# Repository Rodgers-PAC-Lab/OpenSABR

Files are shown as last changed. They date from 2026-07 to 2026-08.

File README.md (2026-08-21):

# OpenSABR

OpenSABR stands for "Open-source System for Auditory Brainstem Response".
This repository was previously named "ABR2025".

## Introduction

This repository contains code to implement the ABR measuring system described
in [Gargiullo et al](https://www.biorxiv.org/content/10.64898/2025.12.17.694771v1), 
as well as the analysis scripts needed to replicate the figures in that paper.

The repository is structured as follows:
- `./` - The toplevel directory, containing this README file
- `./hardware_designs` - Design files, bill of materials, and other information about 
physically building the system.
- `./src/opensabr` - source code for analysis and GUI. Import like `import opensabr`
- `./src/opensabr/gui` - A Python module for running the graphical user interface (GUI) 
to take ABR data. It can be imported like `import opensabr.gui`. This code is 
run on a desktop PC connected to the ABR measuring system hardware.
- `./scripts` - A folder of demo scripts that generate the figures in the
paper, using data that we collected and have shared on Zenodo. These scripts 
are meant to be run one at a time, not imported and called by other scripts. 

## Requirements

We used Python 3.11. Newer versions may also work but we did not test them.
- pyproject.toml contains a list of the required dependencies
- requirements-lock.txt includes the exact versions we used

For the analysis scripts (but not the GUI), the following repository is 
required. It should be on your PYTHONPATH so that it can be imported using
the syntax `import my`.
- `git clone git@github.com:Rodgers-PAC-Lab/my.git`

## Instructions

To build the hardware, refer to the file `./hardware_designs/README.md` for finding code and design files, then refer to the file `OpenSABR Build Guide.pdf` for assembly instructions. 

To run the GUI and measure ABR, refer to the file `./src/opensabr/gui/README`.

To run the analysis scripts and regenerate the figures included in the paper,
refer to the file `./scripts/README`.

## Installation of OpenSABR

A note about our package management approach:
- Repositories that are install-able (i.e., using a method like `pip install` or `python setup.py`) are cloned into `~/installed`
- Repositories that need to be importable (like `import reponame`) but are not install-able are cloned into `~/dev`, which is a directory on `$PYTHONPATH`. Two examples of repositories like this are ABRA and Rodgers-PAC-Lab:my.git

The reason for this distinction is because it can cause errors to mix these two kinds of repositories in the same directory.

### Clone the OpenSABR repo

Run the following commands:

```
cd ~/installed
git clone git@github.com:Rodgers-PAC-Lab/OpenSABR
cd OpenSABR
```

Then pick one of the following installation approaches.
- Option A is easier and does not pin any versions of dependencies, so you will get the newest available
- Option B will download the exact versions of the repositories we used. This is mainly useful for reproducing our results exactly. This approach will only work on linux, since that is what we used.

### Option A: Typical install (no version pins)

```
conda create -n opensabr -c conda-forge python=3.11 pip ipython
conda activate opensabr
conda install -c conda-forge numpy scipy pandas matplotlib tqdm pyqt pyqtgraph pyserial pyarrow seaborn
pip install -e . --no-deps
```

### Option B: Reproducible install from lock (linux-64 only)

```
conda create -n opensabr --file opensabr-conda-lock.txt
conda activate opensabr
pip install -e . --no-deps
```

Now you have installed opensabr. Try `import opensabr` to be sure.

You can stop here if you all you want to do is run or use OpenSABR. You only have to continue if you want to reproduce the comparisons to ABRpresto and ABRA that were made in the paper.

## Installation of other ABR software used as a comparison in the paper

In the paper we also compared our analysis software to two others. If you wish to reproduce this comparison, you will need to install them.

- ABRA, installed into a separate conda environment called "abra"
- ABRpresto, installed into a separate conda environment called "abrpresto"

You do not need to install these others if you just want to run OpenSABR.

### Installing ABRpresto

This is an "install-able" module. 

#### Clone repo

Run the following to install our fork. Our demo scripts require the use of our fork, which contains only minor modifications.

```
cd ~/installed 
git clone git@github.com:Rodgers-PAC-Lab/ABRpresto # our fork
cd ABRpresto
git checkout dev # our branch with fixes
```

Then pick one of the following installation approaches, A (flexible) or B (reproducible), analogous to the options above.

#### Option A: Typical install (no version pins)

```
conda create -n abrpresto -c conda-forge python=3.11 ipython pip
conda activate abrpresto
conda install -c conda-forge numpy scipy pandas matplotlib setuptools_scm pyarrow tqdm
pip install -e . --no-deps
```

#### Option B: Reproducible install from lock (linux-64 only)

```
conda create -n abrpresto --file abrpresto-conda-lock.txt
conda activate abrpresto
pip install -e . --no-deps
```

Now ABRpresto should be installed. Check with `import abrpresto`

### Installing ABRA

This is not an "install-able" module, but it is importable, so it need to go on PYTHONPATH.

#### Clone repo (must be under ~/dev or some location on PYTHONPATH)

```
cd ~/dev
git clone git@github.com:Rodgers-PAC-Lab/abranalysis # our fork
cd abranalysis
git checkout dev # our branch with fixes
```

As above, pick Option A or B.

#### Option A: Typical install (no version pins)

```
conda create -n abra -c conda-forge python=3.11 ipython pip
conda activate abra
conda install -c conda-forge numpy scipy pandas scikit-learn pytorch=*=cpu* keras tensorflow streamlit easydict "altair<5" pyarrow matplotlib tqdm
conda env config vars set PYTHONPATH=$HOME/dev
conda deactivate && conda activate abra   # reload so PYTHONPATH takes effect
```

#### Option B: Reproducible install from lock (linux-64 only)

```
conda create -n abra --file abra-conda-lock.txt
conda activate abra
conda env config vars set PYTHONPATH=$HOME/dev
conda deactivate && conda activate abra   # reload so PYTHONPATH takes effect
```

Now ABRA should be installed. Check with `import abranalyais`

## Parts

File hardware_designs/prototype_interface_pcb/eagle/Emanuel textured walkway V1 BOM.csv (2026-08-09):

Partlist exported from C:/Users/Bill/Dropbox/EAGLE/projects/
Alan Emanuel textured walkway/Emanuel textured walkway V1.sch at 4/9/2025 10:39 AM
Qty | Value | Device | Parts
3 | 1uF | C-USC0805 | C5, C6, C7
1 | 3.3 | TP-040-100 | 3.3
3 | 10uH | L-USL1812 | L1, L2, L3
1 | 22-23-2021 | 22-23-2021 | X1
1 | 74LS14D | 74LS14D | IC10
2 | 78E-5V | RECOM-R-78E | IC8, IC9
1 | 78E-12V | RECOM-R-78E | IC7
3 | 100/35 | CPOL-US140CLH-0810 | C2, C3, C4
3 | 100nF | C-USC0805 | C8, C9, C10
1 | 330/35 | CPOL-US140CLH-1010 | C1
6 | BTS3118N | BTS3118N | IC1, IC2, IC3, IC4, IC5, IC6
1 | EXTRA | ML16 | SV3
1 | I/O-1 | ML16 | SV2
1 | STEPPER | ML16 | SV1
1 | TEENSY_4.0_WITH_24-33 | TEENSY_4.0_WITH_24-33 | U$1
38 | TP-040-100 | TP-040-100 | +5B, 6, 7, 22, 23, 24, 25, 26, 27, 28, 29, 30, 31, 32, 33, E9, E10, E11, E12, E13, E14, E15, E16, EI1, EI2, EI3, EO1, EO2, EO3, MISO, MOSI, RX1, SCK, TX1, VI3, VS1, VS2, VS3
1 | TRCV-175-LARGE | TRCV-175-LARGE | J1

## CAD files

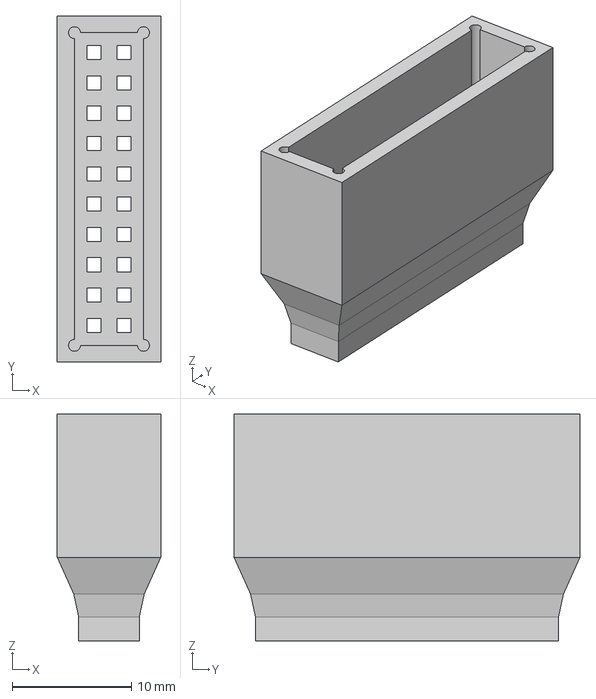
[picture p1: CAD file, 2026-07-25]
hardware_designs/3D_print_designs/2x10 male pin header spacer.step
8.68 x 29.0 x 19.0 mm

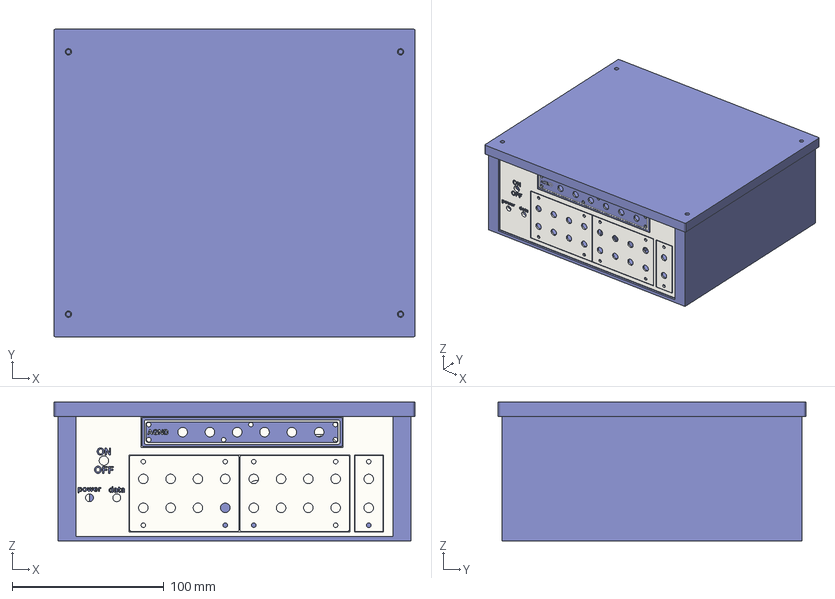
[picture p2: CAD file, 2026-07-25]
hardware_designs/3D_print_designs/Compact ABR enclosure.step
238.0 x 203.0 x 91.5 mm
face plate
Back plate
Lid

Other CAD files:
hardware_designs/3D_print_designs/2x10 male pin header spacer.3mf
hardware_designs/3D_print_designs/2x10 male pin header spacer.f3d
hardware_designs/3D_print_designs/Compact ABR enclosure.3mf
hardware_designs/3D_print_designs/Compact ABR enclosure.f3z

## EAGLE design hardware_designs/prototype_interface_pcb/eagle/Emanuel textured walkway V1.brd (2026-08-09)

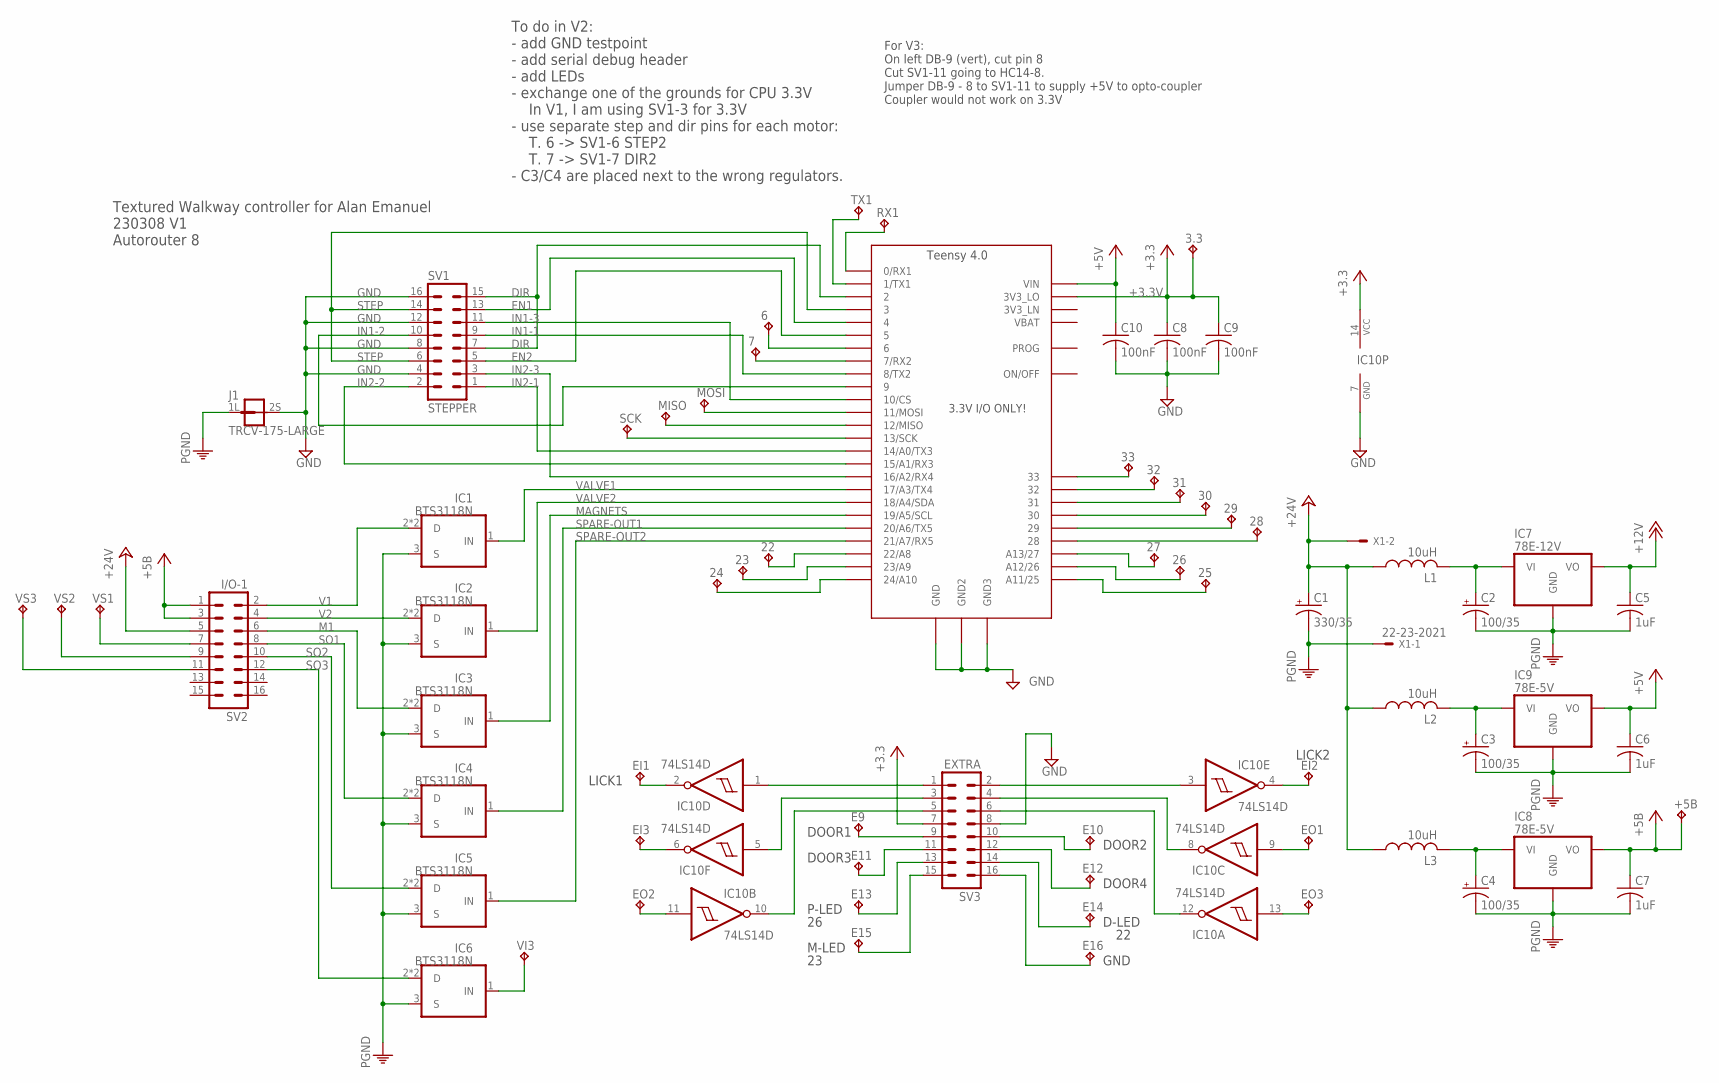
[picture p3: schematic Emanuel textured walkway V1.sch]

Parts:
3.3: 3.3; P1-040-100
6, 7, 22, 23, 24, 25, 26, 27, 28, 29, 30, 31, 32, 33: TP-040-100; P1-040-100
+5B: TP-040-100; P1-040-100
C1: 330/35; 140CLH-1010
C2, C3, C4: 100/35; 140CLH-0810
C5, C6, C7: 1uF; C0805
C8, C9, C10: 100nF; C0805
E9, E10, E11, E12, E13, E14, E15, E16: TP-040-100; P1-040-100
EI1, EI2, EI3: TP-040-100; P1-040-100
EO1, EO2, EO3: TP-040-100; P1-040-100
IC1, IC2, IC3, IC4, IC5, IC6: BTS3118N; SOT223
IC7: 78E-12V; RECOM-R-78E
IC8, IC9: 78E-5V; RECOM-R-78E
IC10: 74LS14D; SO14
J1: TRCV-175-LARGE; JUMPER-TRACE-CONVERT-LARGER-PADS-175
L1, L2, L3: 10uH; L1812
MISO: TP-040-100; P1-040-100
MOSI: TP-040-100; P1-040-100
RX1: TP-040-100; P1-040-100
SCK: TP-040-100; P1-040-100
SV1: STEPPER; ML16
SV2: I/O-1; ML16
SV3: EXTRA; ML16
TX1: TP-040-100; P1-040-100
U$1: TEENSY_4.0_WITH_24-33
VI3: TP-040-100; P1-040-100
VS1, VS2, VS3: TP-040-100; P1-040-100
X1: 22-23-2021

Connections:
+3.3V: 3.3.P$1, C8.1, C9.1, IC10.14 (VCC), SV3.7, U$1.3V3_LO
+5B: +5B.P$1, C7.1, IC8.3 (VO), SV2.1, SV2.3
+5V: C6.1, C10.1, IC9.3 (VO), U$1.VIN
+12V: C5.1, IC7.3 (VO)
+24V: C1.+, L1.1, L2.1, L3.1, SV2.5, X1.2
DIR: SV1.7, SV1.15, U$1.2
EN1: SV1.13, U$1.4
EN2: SV1.5, U$1.5
GND: C8.2, C9.2, C10.2, IC10.7 (GND), J1.2S (2), SV1.4, SV1.8, SV1.12, SV1.16, SV3.8, U$1.GND, U$1.GND2, U$1.GND3
IN1-1: SV1.9, U$1.8 (8/TX2)
IN1-2: SV1.10, U$1.9
IN1-3: SV1.11, U$1.10/CS
IN2-1: SV1.1, U$1.14/A0 (14/A0/TX3)
IN2-2: SV1.2, U$1.15/A1 (15/A1/RX3)
IN2-3: SV1.3, U$1.16/A2 (16/A2/RX4)
M1: IC3.2 (D), IC3.4 (D), SV2.6
MAGNETS: IC3.1 (IN), U$1.19/A5/SCL
unnamed: C2.+, IC7.1 (VI), L1.2
unnamed: C4.+, IC8.1 (VI), L3.2
unnamed: SV2.9, VS2.P$1
unnamed: SV2.11, VS3.P$1
unnamed: C3.+, IC9.1 (VI), L2.2
unnamed: IC6.1 (IN), VI3.P$1
unnamed: MOSI.P$1, U$1.11/MOSI
unnamed: MISO.P$1, U$1.12/MISO
unnamed: SV2.7, VS1.P$1
unnamed: SCK.P$1, U$1.13/SCK
unnamed: 22.P$1, U$1.22/A8
unnamed: 23.P$1, U$1.23/A9
unnamed: 24.P$1, U$1.24 (24/A10)
unnamed: 33.P$1, U$1.33
unnamed: 32.P$1, U$1.32
unnamed: 31.P$1, U$1.31
unnamed: 30.P$1, U$1.30
unnamed: 29.P$1, U$1.29
unnamed: 28.P$1, U$1.28
unnamed: 27.P$1, U$1.27 (A13/27)
unnamed: 26.P$1, U$1.26 (A12/26)
unnamed: 25.P$1, U$1.25 (A11/25)
unnamed: RX1.P$1, U$1.0/RX (0/RX1)
unnamed: TX1.P$1, U$1.1/TX (1/TX1)
unnamed: 6.P$1, U$1.6
unnamed: 7.P$1, U$1.7 (7/RX2)
unnamed: IC10.1 (I), SV3.1
unnamed: IC10.3 (I), SV3.2
unnamed: IC10.5 (I), SV3.3
unnamed: IC10.8 (O), SV3.4
unnamed: IC10.10 (O), SV3.5
unnamed: IC10.12 (O), SV3.6
unnamed: E9.P$1, SV3.9
unnamed: E11.P$1, SV3.11
unnamed: E13.P$1, SV3.13
unnamed: E15.P$1, SV3.15
unnamed: E10.P$1, SV3.10
unnamed: E12.P$1, SV3.12
unnamed: E14.P$1, SV3.14
unnamed: E16.P$1, SV3.16
unnamed: EI1.P$1, IC10.2 (O)
unnamed: EI3.P$1, IC10.6 (O)
unnamed: EI2.P$1, IC10.4 (O)
unnamed: EO3.P$1, IC10.13 (I)
unnamed: EO1.P$1, IC10.9 (I)
unnamed: EO2.P$1, IC10.11 (I)
PGND: C1.-, C2.-, C3.-, C4.-, C5.2, C6.2, C7.2, IC1.3 (S), IC2.3 (S), IC3.3 (S), IC4.3 (S), IC5.3 (S), IC6.3 (S), IC7.2 (GND), IC8.2 (GND), IC9.2 (GND), J1.1L (1), X1.1
SO1: IC4.2 (D), IC4.4 (D), SV2.8
SO2: IC5.2 (D), IC5.4 (D), SV2.10
SO3: IC6.2 (D), IC6.4 (D), SV2.12
SPARE-OUT1: IC4.1 (IN), U$1.20/A6 (20/A6/TX5)
SPARE-OUT2: IC5.1 (IN), U$1.21/A7 (21/A7/RX5)
STEP: SV1.6, SV1.14, U$1.3
V1: IC1.2 (D), IC1.4 (D), SV2.2
V2: IC2.2 (D), IC2.4 (D), SV2.4
VALVE1: IC1.1 (IN), U$1.17/A3 (17/A3/TX4)
VALVE2: IC2.1 (IN), U$1.18/A4/SDA

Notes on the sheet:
Textured Walkway controller for Alan Emanuel 230308 V1 Autorouter 8
To do in V2: - add GND testpoint - add serial debug header - add LEDs - exchange one of the grounds for CPU 3.3V In V1, I am using SV1-3 for 3.3V - use separate step and dir pins for each motor: T. 6 -> SV1-6 STEP2 T. 7 -> SV1-7 DIR2 - C3/C4 are placed next to the wrong regulators.
LICK1
LICK2
DOOR1
DOOR3
DOOR2
DOOR4
P-LED
M-LED
D-LED
GND
For V3: On left DB-9 (vert), cut pin 8 Cut SV1-11 going to HC14-8. Jumper DB-9 - 8 to SV1-11 to supply +5V to opto-coupler Coupler would not work on 3.3V

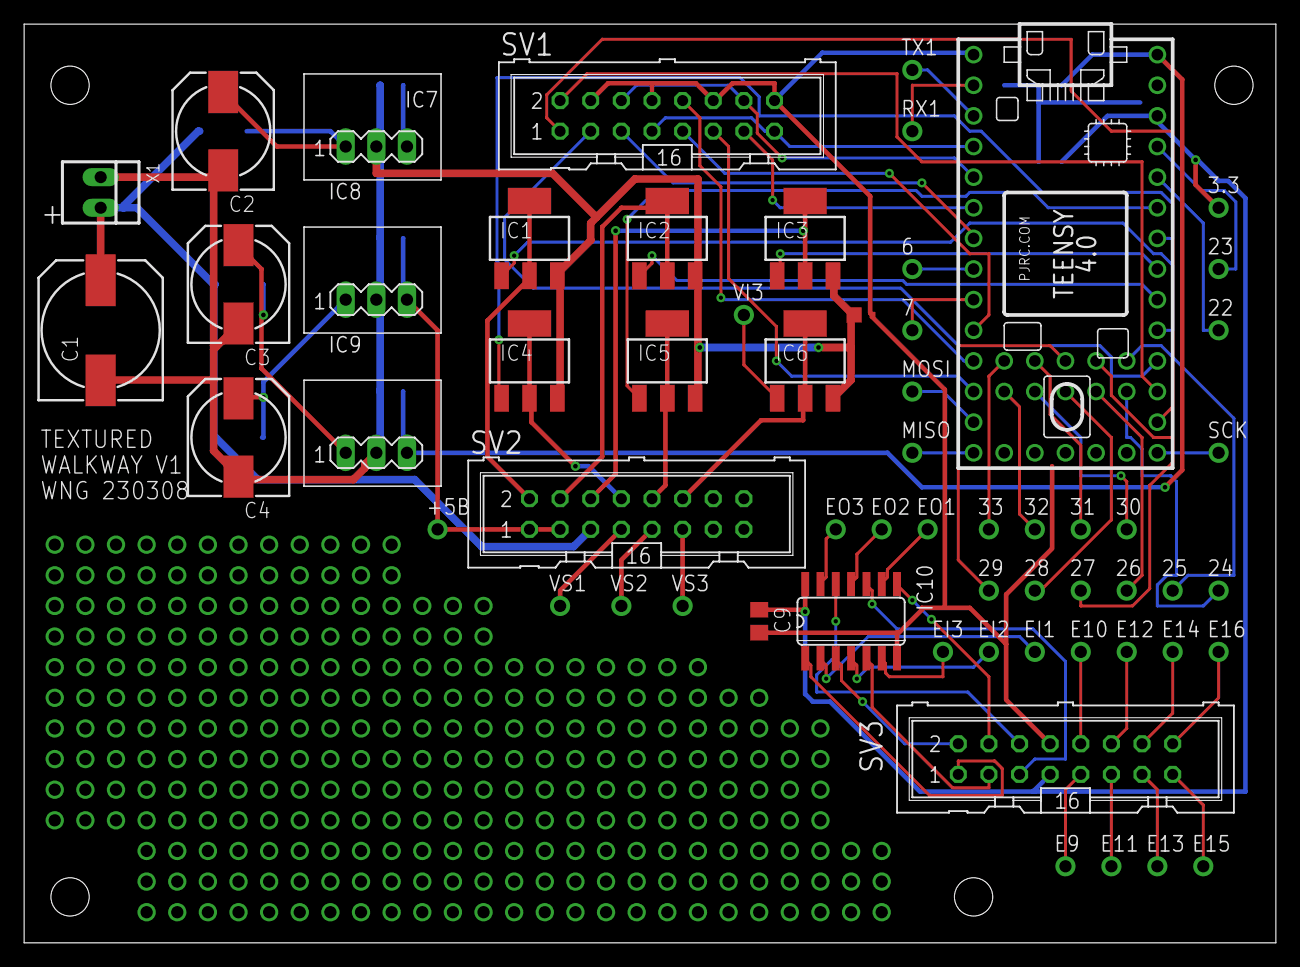
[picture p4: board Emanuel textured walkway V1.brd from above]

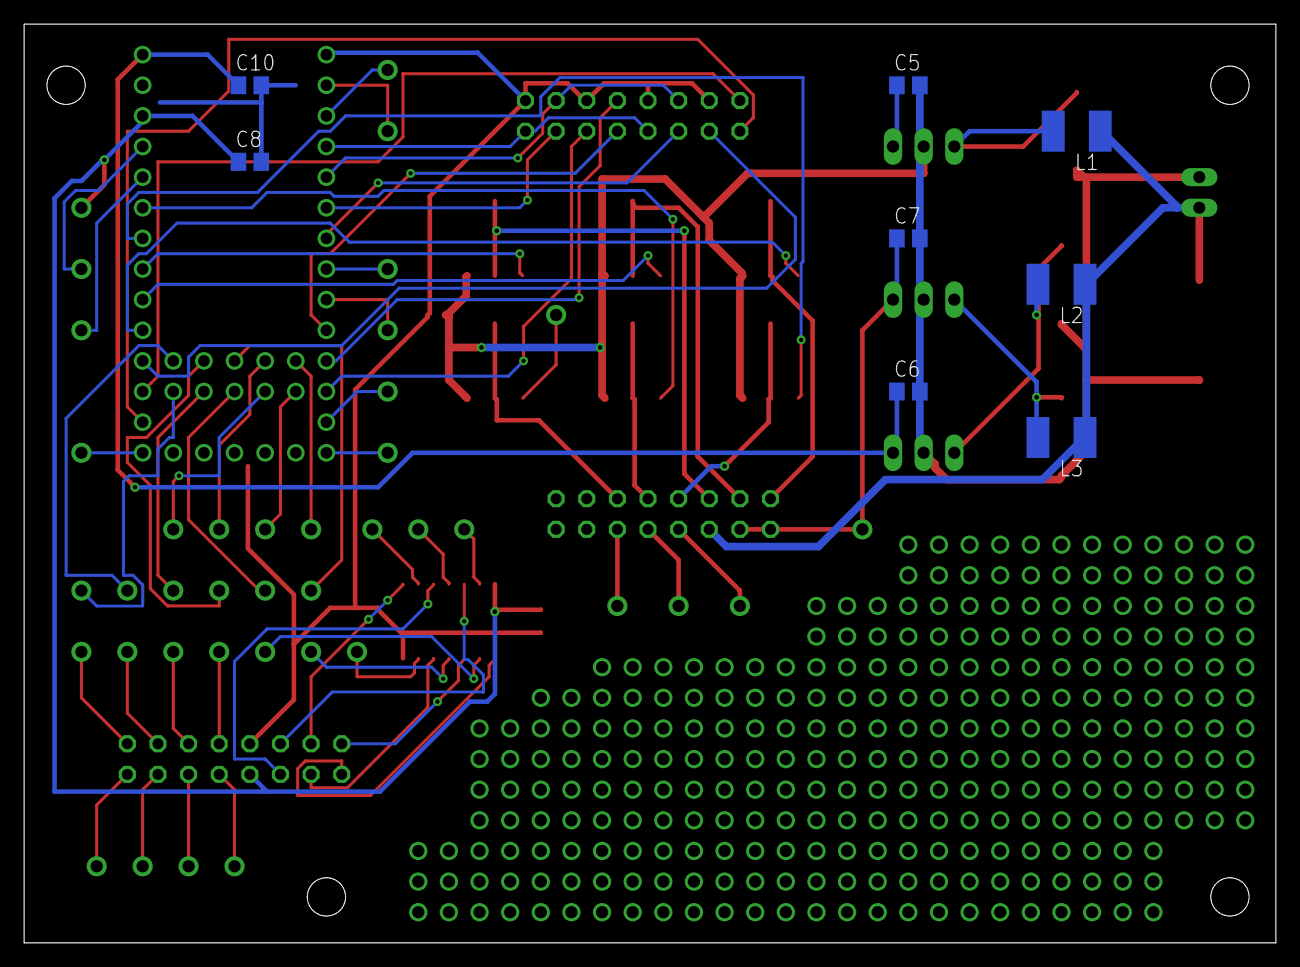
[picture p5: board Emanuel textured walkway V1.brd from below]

Board: 2 copper layers, 103.8 x 76.2 mm, 68 parts (8 on the bottom side), 74 nets.

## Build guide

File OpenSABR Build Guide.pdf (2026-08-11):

# OpenSABR Build Guide

Latest Revision: 2026-08-10

This guide explains how to build OpenSABR (Open-source System for Auditory Brainstem Response). Further information is available in the BioRxiv preprint (https://doi.org/10.64898/2025.12.17.694771) and the accompanying GitHub repository. (https://github.com/Rodgers-PAC-Lab/OpenSABR)

### Note on previous versions

For all experiments in the paper, we used a prototype version of OpenSABR with a different enclosure and interface PCB. We recommend that all new users follow the build guide for the current version of the system, described in this document. However, for reproducibility and record-keeping purposes only, the old build guide for the prototype version is available in the Supplemental Materials of the BioRxiv preprint (https://www.biorxiv.org/content/10.64898/2025.12.17.694771v1.supplementary-material) and the old designs are available in the ‘prototype_interface_pcb’ folder on our github. (https://github.com/Rodgers-PAC-Lab/OpenSABR/tree/main/hardware_designs/prototype_interface_pcb) Again, new users are encouraged to build the updated version described below.

### Overview of the system

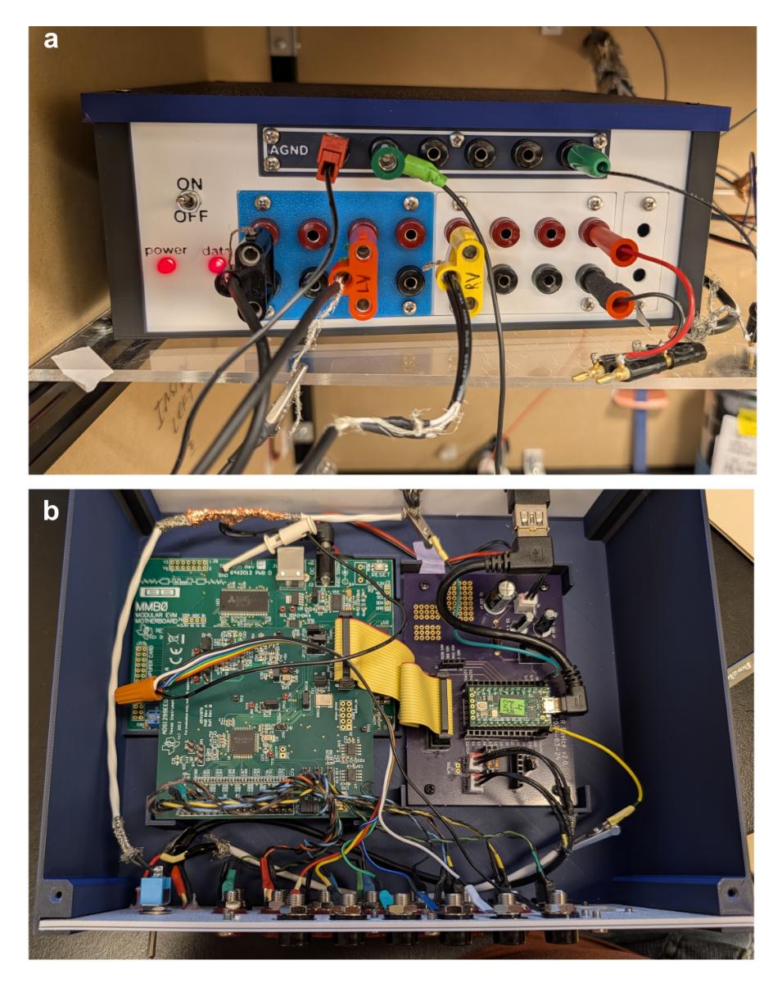
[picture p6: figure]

Figure 1. Hardware. a) Front panel of the enclosure. b) Inside of the enclosure with the top removed. Daughterboard and motherboard (green) on left side and interface PCB (purple) on right side, connected with a ribbon cable (yellow).

Main components and availability: OpenSABR’s main electronics are Texas Instruments’ ADS1299 development kit (consisting of a MMB0 motherboard and ADS199 daughterboard), a Teensy 4.0 microcontroller, and a custom interface printed circuit board (PCB) all housed in a 3D printed enclosure (Fig. 1). You will also need some custom cables, electrodes, and a Linux PC. All the components are commercially available and we provide a full Bill of Materials. (https://docs.google.com/spreadsheets/d/1TG8ZKOnROT0feTbqC7P34zV8RUbSuSlzaugLh0SKst8/edit?usp=sharing)

Interface PCB. The interface PCB can be ordered from our project shared on OSH Park, (https://oshpark.com/shared_projects/cb0X7Rhg) or you can get the PCB designs (Fig. 2) from our Github’s ‘hardware designs’ folder (https://github.com/Rodgers-PAC-Lab/OpenSABR/tree/main/hardware_designs/ABR_device_compact) and order the board from your preferred PCB manufacturer. We provide the files for the 3D printed enclosure and custom board spacers in the ‘3D print designs’ (https://github.com/Rodgers-PAC-Lab/OpenSABR/tree/main/hardware_designs/3D_print_designs) section of our github.

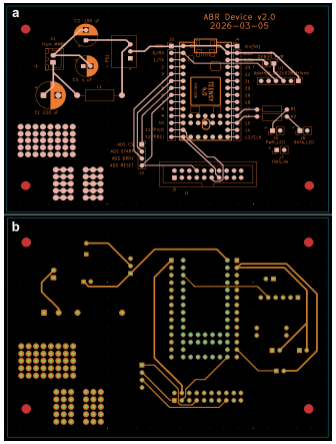
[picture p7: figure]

Figure 2. Layout of interface PCB. a) Front. b) Back.

Power: OpenSABR uses the MMB0 motherboard to provide power to the ADS1299 daughterboard and interface PCB. The interface PCB houses a voltage regulator to convert the MMB0’s 9V power into the 5V power required by the Teensy.

Data and control signals: Raw voltage is collected at the electrodes, recorded by the ADS1299 daughterboard, and sent to the Teensy using 4-wire SPI protocol. The Teensy collects this data as packets, adds headers, and sends the packets to the desktop computer’s GUI over USB (Fig. 3).

The Teensy controls the ‘power’ and ‘data’ indicator LEDs on the front panel of the enclosure. The ‘data’ indicator blinks when a recording is in process. It may stay on after the recording has ended, but this does not mean data is still recording.

The Teensy uses its TX and RX lines to send debug information to the optional USB-to-serial converter, Adafruit’s CP2102N Friend. The CP2102N Friend uses a second USB cable to send data to the computer, which can be displayed in a serial monitor program such as minicom.

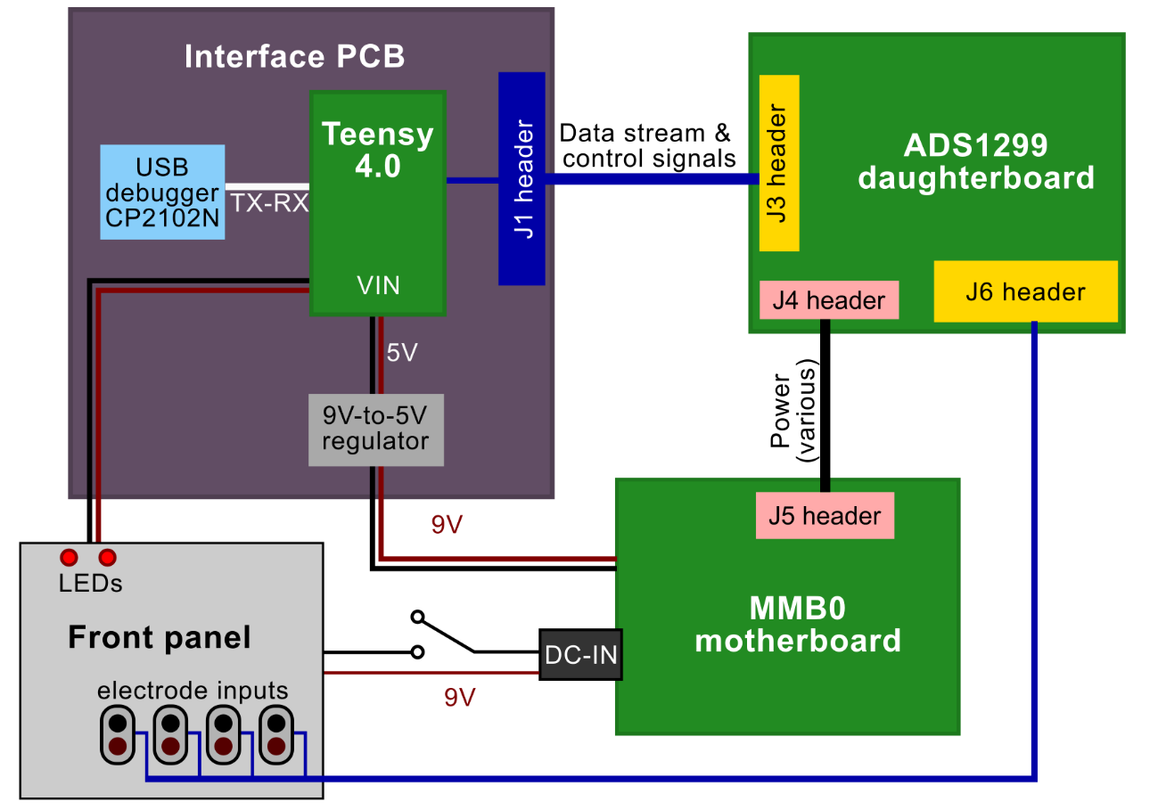
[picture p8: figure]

Figure 3. Overall schematic of the hardware inside the enclosure. The interface PCB (purple; upper left) houses the Teensy, the USB debugger, a power regulator, and a J6 header connected to the ADS1299 daughterboard. The ADS1299 daughterboard (green; upper right) houses the ADS1299 itself. The MMB0 motherboard (green; lower right) provides power. The front panel (gray; lower left) provides banana jacks for signal inputs and status indicator LEDs.

### Physical enclosure

We designed a 3D printable enclosure for the device, which are the ‘Compact ABR enclosure’ files in 3D print designs folder of (https://github.com/Rodgers-PAC-Lab/OpenSABR/tree/main/hardware_designs/3D_print_designs) our github. The main body holds the interface PCB and MMB0 motherboard. The rear panel has holes for a power jack and feed-through USB adapter. The front panel (Fig. 4) has holes for a power switch, power and data indicator LEDs, and four slots to screw on modular faceplates:

- a long top faceplate with 8 banana jacks for grounding
- two faceplates, each with four channels of banana jacks for electrodes
- a single-channel faceplate on the far right for a TRIG IN channel

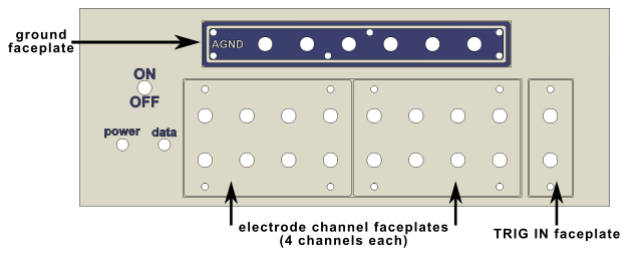
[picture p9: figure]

Figure 4. Design of front panel with modular faceplates labeled. This design allows you to print colored text without requiring a multi-color printer. Since the text is embossed, use your preferred slicing software to insert a pause after it’s printed the bottom of the embossed text. Swap to the filament color you want for the main enclosure and resume the print.

### Populating the interface PCB

First, solder all components to the interface PCB (Fig. 5a):

- A 2-pin JST-XH header on the X1 header for power input
- 2-pin JST-XH headers on the J5, J6, and J7 for the LEDs and optional TRIG_IN input
- R1 and R2 resistors for the power and data LEDs respectively (use appropriate value for your LEDs)
- A 9-to-5V step-down voltage regulator in PS1
- A 220 µF capacitor in C1
- A 100 µF capacitor in C2
- A 1 µF capacitor in C3
- A 10 µH inductor in L1
- Standard 2.54mm pitch female headers in the footprints provided
- A 2-pin 2.54mm-pitch male header in J8 (to power the USB debugger from Teensy power, add a jumper to short these two pins)

Make 2 cables between the power and data indicator LEDs to plug into the J5 and J6 connectors respectively (Fig. 5b).

The bottom left corner of the interface PCB has through-holes, which may be helpful for prototyping any addons or edits to the device. The lower rows of through-holes are shorted in breadboard-style rows, so see the PCB layout before using these (Fig. 2).

Screw the interface PCB into the enclosure base at the 4 corners using M3 screws. The holes are slightly under-sized so the screws should bite into the plastic and form threads.

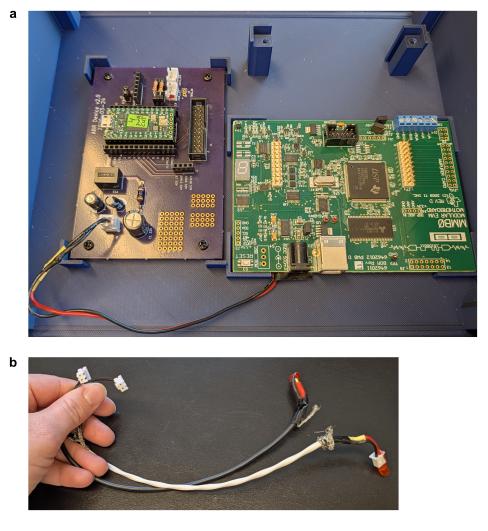
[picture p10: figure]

Figure 5. a) Base of the enclosure. Purple interface PCB (left) with all components soldered except for TRIG IN jack which we did not use. Green MMB0 motherboard (right) with power cable to the interface PCB. b) Cables for the power and data indicator LEDs. LEDs can be soldered directly to the wire, or the plugged into a female connector at the end of the wire.

### Other devices on the interface PCB

USB debugger. The interface PCB’s U1 connector is for an optional serial-to-USB debugger (Adafruit CP2102N Friend). Its TX and RX pins connected to Teensy pins 0 and 1 respectively. Shorting the pins of the J8 DEBUG_PWR header will connect the debugger’s power to the 3.3V power from the Teensy, but the debugger typically is powered by its own USB cable so this is not necessary.

Teensy 4.0. Normally the Teensy would be powered by the USB connection, but we wanted it to be powered instead by the MMB0 motherboard so that it could be powered off and on by the front panel. To prevent contention on these power lines, it is necessary to cut the trace between the VIN and VUSB pads on the back of the Teensy (Fig 6a). Then add male headers to the Teensy’s through-holes and plug it into the female headers on the interface PCB.

### Setting up the MMB0 motherboard

Solder a power cable to the positive and ground leads of the MMB0's DC-IN jack (Fig 6b). We recommend using hot glue or electrical tape to provide mechanical stability here, because wire-to-board soldering puts stress on the wire near the solder joint. Terminate the other end of this cable with a JST-XH connector and plug it into the interface PCB’s X1 power connector.

Verify that on the MMB0 board jumper J12 is connected, J13A is not connected, and jumper J13B is connected. At this point, it should look like the picture in Figure 5a.

We made an adapter cable to insert a power switch into the circuit (Fig. 6c). The input jack (Same Sky PJ-011B) is mounted to the back panel, and the front panel’s power switch interrupts the circuit before the right-angle plug is plugged into the MMB0’s DC-IN jack. When soldering to the input jack, note that there are three pins and only two will provide power (Fig. 6d). The third pin is designed to provide power from a battery backup and will automatically disconnect when anything is plugged into the jack, so be sure to use the correct pin when soldering this cable.

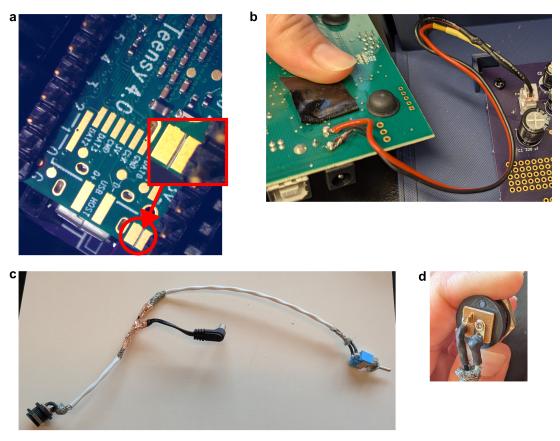
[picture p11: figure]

Figure 6. Powering OpenSABR. a) The cut trace between the VIN and VUSB pads on the back of the Teensy board. b) Power cable to the interface PCB, soldered to the bottom of the MMB0’s DC-IN jack. c) Power cable adapter which inserts a power switch for the device before the MMB0’s DC-IN jack. d) Close-up of the power input jack. The third unused pin is not connected and will not provide power.

### Adding the ADS1299 daughterboard

The ADS1299 daughterboard is typically stacked on top of the MMB0 motherboard with three headers: the MMB0 motherboard labels these as J4 and J7 for data, and J5 for power. For OpenSABR we use the MMB0 to provide power without sending any data between the MMB0 and daughterboard.

Print two of the ‘2x10 male pin header spacer’ from the 3D print designs (https://github.com/Rodgers-PAC-Lab/OpenSABR/tree/main/hardware_designs/3D_print_designs) in our Github. Slide these over the J4 and J7 headers on the MMB0 (Fig. 7a), where they can provide mechanical connection without electrical connection. Use a 2x5 stacking header to connect the MMB0’s J5 connector to the daughterboard’s J4 connector. Once the boards are stacked, use two M3 screws to fasten the daughterboard to the posts on the enclosure’s base.

OpenSABR uses almost all of the factory default settings on the ADS1299 daughterboard, which you can verify by checking Table 1 of the development kit’s datasheet here. (https://www.ti.com/tool/ADS1299EEGFE-PDK#tech-docs) The exception is the jumpers JP2 and JP20 on the upper right of the board, which should be configured as shown in Figure 7b to use the +/- 2.5V bipolar power supply configuration. The board’s white markings use a notched corner to mark pin 1, and these jumpers are both numbered right to left. JP2 should have pins 1-2 shorted and JP20 should have pins 2-3 shorted.

Use the 2x10 ribbon cable to connect the daughterboard’s J3 header to the interface PCB’s J1 header. Make sure the cable is plugged in the right orientation (Fig. 7c) with the daughterboard J3’s CLKSEL pin connected to pin 1 on the interface PCB’s J1 pin 1. Table 1 lists the pinout for the daughterboard’s J3 connector and the corresponding pin assignments on the Teensy, as well as other important Teensy pin assignments.

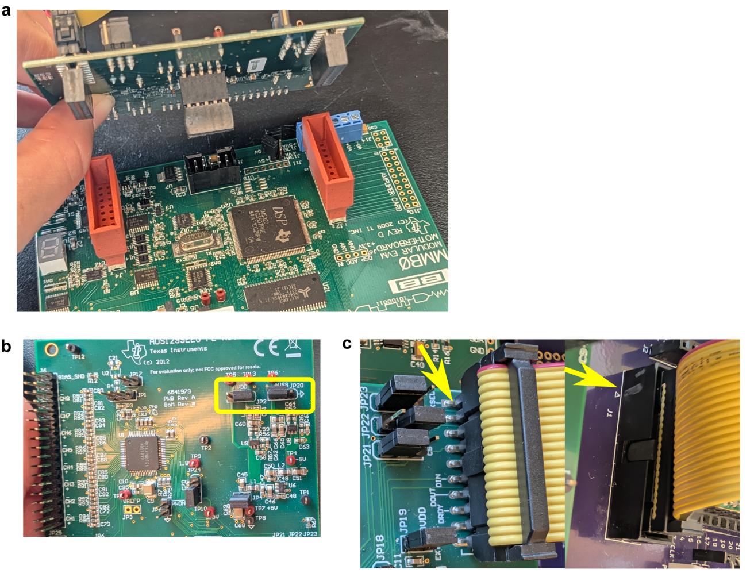
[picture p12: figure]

Figure 7. Daughterboard setup. a) Connectors between MMB0 motherboard and ADS1299 daughterboard. The MMB0’s J4 and J7 headers have 3D printed hollow spacers. The MMB0’s J5 header was connected to the daughterboard’s J4 header using stacking headers. b) The daughterboard with JP2 and JP20 outlined in yellow. c) The correct orientation of the ribbon cable on the daughterboard (left) and interface PCB (right). Yellow arrowheads designate pin 1 on the connectors.

ADS daughterboard J3 | Teensy pin assignments
(2x10 header) | Pin number | Function
J3 pin number Function | 0 | RX1 (to debug's TX)
1 | START | 1 | TX1 (to debug's RX)
2 | N/C | 3 | DRDY
3 | CLK | 4 | START
4 | N/C | 5 | CS
5 | N/C | 6 | RESET
6 | N/C | 11 | MOSI
7 | CS | 12 | MISO
8 | RESET | 13 | CLK
9 | N/C | 14 | TRIG IN (Front panel)
10 | GND | 15 | DATA LED
11 | DIN | 16 | POWER LED
12 | N/C | GND | GND
13 | DOUT | VIN | 5V from regulator
14 | N/C

### 15 DRDY

16 | N/C
17 | N/C
18 | N/C
19 | N/C
20 | N/C

Table 1. Pinout of ADS1299 daughterboard’s J3 header and Teensy GPIO pins. The left table lists the pins in the J3 header on the ADS daughterboard and corresponding J1 header on the interface PCB. The right table lists the Teensy’s pin assignments and other connections.

### Assembling front and back panels

Mount the power switch in the front panel as shown in Figure 8a, making sure that the orientation of the switch matches the orientation of the ON/OFF label on the panel. Push the LEDs into the ‘power’ and ‘data’ holes and use hot glue or tape to secure them.

Mount the power jack and USB adapter in the back panel as shown in Figure 8b. The USB adapter (CLIFF Electronics CP30205NM3B) uses M3 screws.

Slide the front and back panels into the grooves on the enclosure base. Use M3 screws to attach the AGND faceplate to the front panel.

Plug the power cable’s right-angle plug into the MMB0 motherboard’s DC-IN jack. Use the right-angle USBmicro-to-USB-A cable to connect the Teeny 4.0 to the USB adapter. Use short alligator-to-M-pin jumpers to connect any cable shielding to the Teensy’s ground pins. At this point, it should look like Figure 8c.

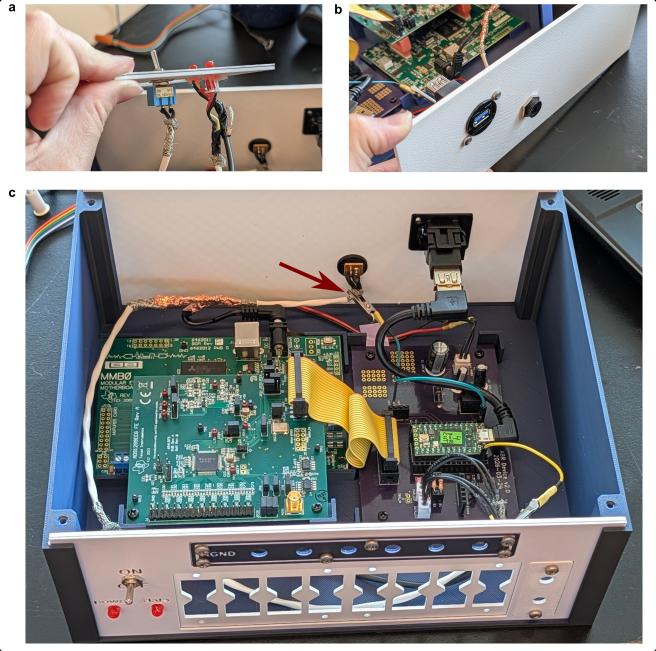
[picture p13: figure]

Figure 8. a) Front panel with power switch and LEDs mounted. b) Back panel with USB adapter and power jack mounted. c) OpenSABR with front and back panels installed. Red arrow indicates grounding clip connecting the power cable shielding to the Teensy’s ground.

### Assembling the electrode and ground inputs

Each electrode input is a pair of wires soldered to the solder lug of one red and one black banana jack, terminating in a 2-pin standard 2.54mm pitch female header (Fig. 9a). Make 8 of these (9 if you intend to use the TRIG-IN jack).

Mount the banana jacks on the electrode channel faceplates as shown in Figure 9a. Feed the cables through the front panel and plug them into the daughterboard’s J6 header as shown in Figure 9b, using only the even numbered pins (right side). Follow the white print on the daughterboard, with channel one’s positive input at the bottom and channel 8’s negative input closest to the top. The top pins next to ‘BIAS_SHD’ are reserved for a bias configuration which we did not use. Screw the electrode channel faceplates to the front panel with M3 screws.

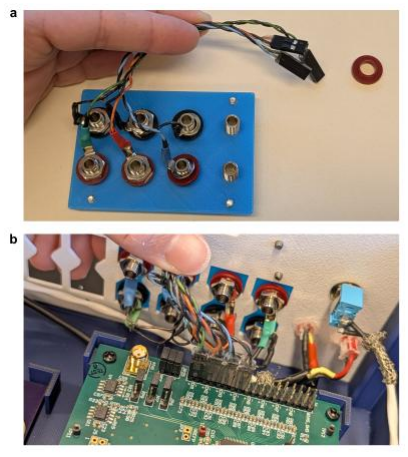
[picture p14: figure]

Figure 9. a) Electrode input jacks with cables, mounted to the electrode channels faceplate. b) Electrode channels faceplate mounted to the front panel, with electrode cables plugged into the daughterboard’s J6 header.

Screw the faceplate for the grounding jacks to into the front panel at the top (Fig. 4). Use a wire nut to connect 7 wires. Solder 6 of these wires to the solder lugs of 6 black banana jacks (Mueller Electric BU-00233-0) as shown in Figure 10a. Solder the 7th wire to a micrograbber (Pomona 4233-9) and hook this into the TP3 test point on the upper left of the MMB0 motherboard (Figure 10b), which is connected to ground. Mount these analog ground (AGND) jacks to the ground faceplate.

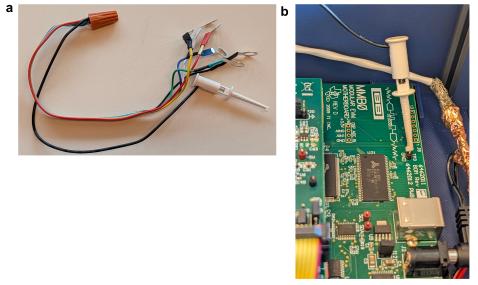
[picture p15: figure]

Figure 10. a) Wire nut with 7 wires—6 soldered to solder lugs for the ground input jacks, and one soldered to a micrograbber. b) Micrograbber hooked onto the MMB0 motherboard’s TP3 test point, which is grounded.

At this point everything should look like Figure 1b and OpenSABR is almost complete. Attach the lid with M3 screws at the corners to finish the enclosure.

### Custom cabling

The last step is making the custom electrode cable as described in the paper. Solder a minigrabber (Pomona 3925) to the end of each wire of a shielded 3-conductor cable about 90 cm long (Fig. 11a). The micrograbbers will hold onto the stripped end of the Left, Right, and Vertex electrode wires. We recommend labeling the micrograbbers accordingly.

Cut 3 short lengths of two-conductor shielded cable for the LR, LV, and RV channels. On the loose end of the 3-conductor electrode cable, split the 3 electrode wires out into the 6 channel wires according to what each channel measures as shown in Figure 11b. For example, the R electrode wire should be split into the negative wire of LR and positive wire of RV. After soldering, add some foil or extra shielding to make sure that the shielding is continuous across this cross-over point.

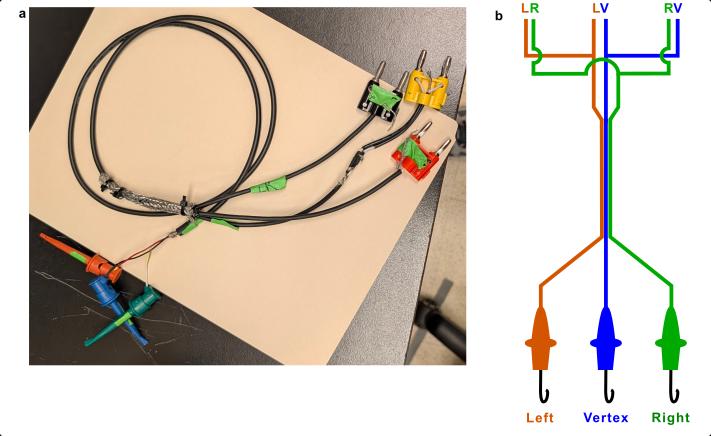
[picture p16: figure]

Figure 11. a) Photo of electrode cable with 3 micrograbbers on one end and 3 double banana plugs on the other. Zip-tied shielding sleeve covers the area where the 3-conductor cable splits into the 6 wires for 3 channels, and the shielding sleeve contacts the shielding for all of the individual cables. b) Schematic of cable wiring, color-coded by which electrode they connect to.

### Description of the Teensy software

The Teensy 4.0 is a 32-bit Arduino-compatible microprocessor board running at 600MHz. It was programmed using the C++ language in the Arduino IDE. The Teensy controls the ADS1299 and acts as an intermediary between the ADS1299 and a computer program, accepting commands from the computer and facilitating high speed data transfer for display, analysis and logging. We have written such programs in National Instruments’ Labview and in Python for a Linux PC. The Teensy’s code and Linux-based Python GUI are publicly available on our github page (https://github.com/Rodgers-PAC-Lab/OpenSABR). There are several ways to upload the program to the Teensy, including from the Arduino IDE or from VSCode using the PlatformIO plugin.

The Teensy interfaces with the ADS1299 via a standard 4-wire SPI bus including chip-select (CS), serial clock (SCLK), Teensy data out (MOSI/PICO) and Teensy data in (MISO/POCI). Other ADS1299 pins required for the interface are START, RESET and data ready (DRDY).

The ADS1299 power-up sequence requires setting chip-select active (CS) then activating RESET for at least 9 µs before releasing CS. Before starting a recording, you can change the ADS1299 control registers to set the desired sampling rate and gain. Sampling rate will be the same for all channels, but each channel can have its own gain from the allowed values (1, 2, 4, 6, 8, 12, 24). We use a gain of 24 for neural channels and a gain of 1 for the audio channel.

A sampling session begins by sending the read data continuous (RDATAC) and START commands. The falling edge of DRDY signals that the latest sample is ready for reading and triggers an interrupt routine to store the new data. For example, at the highest sampling rate of 16KHz, DRDY falls every 62.5 µs. Teensy software utilizes an interrupt-driven double-buffered sampling method. All 8 channels are read at once and stored to one of the two buffers. When one buffer is full, the other buffer becomes the active buffer and the full buffer is sent over USB to the computer program. This allows data to be captured and processed continuously without dropping samples.

One 8-channel sample from the ADS1299 includes 3 status bytes plus 3 data bytes/channel, for a total of 27 bytes. Our buffers, or packets, hold 500 samples. Before sending a packet, we prepend a 12-byte header and promote samples from 24 bits to 32-bit integers, making the packet size 16,012 bytes. At 16KHz sample rate a buffer fills in 31.25 ms, for a data rate of 512 Kbytes/sec. The Teensy’s USB 2.0 full speed interface has a typical maximum data rate of 30-40 Mbytes/sec, so we are well within the USB bus capability.

The packet header contains fields for packet sequence number, number of samples and channels, sampling rate, and an input trigger marker. The sequence number allows the receiving program to detect lost packets. The trigger marker is a number between 0 and 499 that marks the packet sample on which an external trigger was detected, allowing the receiving program to calculate the sample at which the trigger occurred. Currently this trigger is unused.

ADS1299 provides auxiliary functions for measuring electrode impedance and lead-off detection. By setting the appropriate control registers, an internal current source can be routed to the electrodes. Electrode impedance can be determined from the resulting voltage at the electrode. Similarly, an out of range electrode impedance can be used to detect a lead-off condition.

Transfer of data from the Teensy to the high-level program has been explained above. It uses a binary format due to the high data rate required. On the other hand, commands from the high-level program to Teensy involve a single letter to denote the command and a few numeric parameters. Simple ASCII strings suffice for this and simplify decoding on the Teensy end. Commands supported are:

U - Set up sampling. Parameters: number of channels, sample rate, flags and gain of each channel

S - Start sampling, with parameters previously given by U

I - Inquire if receiver is present. Used at program startup to make sure the Teensy and ADS1299 are operational.

Q - Query specifications. Returns the capabilities of the ADS1299, such as max sample rate, max number of channels, etc.

X - Stop sampling

After sending the Start command, the high-level program polls the USB bus to see if data is available. If so, it reads the packet header and then the raw data. The Stop command is sent when the session completes.
